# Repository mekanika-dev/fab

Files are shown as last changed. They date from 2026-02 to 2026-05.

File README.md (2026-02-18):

# Fab CNC

> Fab is a large-format CNC milling machine to boost your production. It allows you to produce a wide range of materials every day at high speed and with precision.

- [Assembly Guide & Documentation](https://support.mekanika.io/products/fab-cnc)
- [Shop](https://www.mekanika.io/en/store/be/fab/)
- [Contact](https://www.mekanika.io/contact-us/)

Fab CNC Milling Machine

## Repository Structure

- **`bom/`** - Bill of Materials
- **`cad/`** - CAD files
- **`docs/`** - Documentation files

The Bill of Materials is available as a CSV file, which is dynamically updated from our ERP. We recommend using this **[web viewer](https://mekanika-dev.github.io/data-sync-actions/odoo/bom-viewer.html)** to browse its content.

All 3D assembly files are made in STEP format and compatible with many CAD software. Please note that you will need Git LFS installed to clone or pull the repo correctly, since these files exceed 100MB.

The design files can also be viewed in web browsers using these links:

- [Fab](https://a360.co/4mOqgvm)
- [Fab Control Unit](https://a360.co/46sqwel)

## Assembly Guide

The assembly guide is available on our [support website](https://support.mekanika.io/products/fab-cnc). If you have feedback or want to raise an issue about a specific assembly step, you can use the feedback buttons available on each step's page.

## Community

Mekanika encourages collaborative design and innovation. We welcome:

- Designers and engineers to contribute
- Feedback on design variations
- Any discussions around or products and potential improvements

Don't hesitate to join us on our [Discord](https://discord.gg/n7RsBtUdGc)

## License

This project is licensed under the **CERN Open Hardware Licence Version 2 - Strongly Reciprocal** ([CERN-OHL-S v2](https://ohwr.org/cern_ohl_s_v2.pdf))

For the complete license terms, see REUSE.toml

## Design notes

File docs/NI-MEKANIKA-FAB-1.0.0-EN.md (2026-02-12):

---
title: "USER MANUAL: CNC FAB"
css: style.css
---

<div class="cover-page" style="text-align: center;">

Logo Mekanika

<h4 style="margin-bottom: 0;">3-AXIS CNC MILLING MACHINE</h4>

<hr style="width: 200px; margin: 10px auto; color:#000 !important;"/>

<h4 style="margin-top: 0;">FAB MODEL V1.0</h4>

Fab ISO View

**ORIGINAL MANUAL**
<br/>
Version: 1.0.0-EN
<br/>
Revision Date: November 2025

</div>

## TABLE OF CONTENTS

#### 1. GENERAL INFORMATION

<ul style="list-style-type: none;">
  <li>1.1 <a href="#11-manufacturer-identification">Manufacturer identification</a></li>
  <li>1.2 <a href="#12-ce-declaration-of-conformity">CE Declaration of Conformity</a></li>
  <li>1.3 <a href="#13-intended-use">Intended use</a>
    <ul style="list-style-type: none;">
      <li>1.3.1 <a href="#131-normal-use">Normal Use</a></li>
      <li>1.3.2 <a href="#132-prohibited-uses">Prohibited uses</a></li>
    </ul>
  </li>
  <li>1.4 <a href="#14-authorized-personnel">Authorized personnel</a>
    <ul style="list-style-type: none;">
      <li>1.4.1 <a href="#141-minimum-requirements">Minimum requirements</a></li>
      <li>1.4.2 <a href="#142-restrictions">Restrictions</a></li>
    </ul>
  </li>
</ul>

#### 2. SAFETY

<ul style="list-style-type: none;">
  <li>2.1 <a href="#21-safety-instructions-by-risk-level">Safety instructions by risk level</a></li>
  <li>2.2 <a href="#22-personal-protective-equipment">Personal protective equipment</a>
    <ul style="list-style-type: none;">
      <li>2.2.1 <a href="#221-mandatory-ppe">Mandatory PPE</a></li>
      <li>2.2.2 <a href="#222-dress-code">Dress Code</a></li>
    </ul>
  </li>
  <li>2.3 <a href="#23-safety-devices">Safety devices</a>
    <ul style="list-style-type: none;">
      <li>2.3.1 <a href="#231-emergency-stop">Emergency stop</a></li>
      <li>2.3.2 <a href="#232-limit-switches">Limit switches</a></li>
      <li>2.3.3 <a href="#233-dust-shoe">Dust shoe</a></li>
    </ul>
  </li>
</ul>

#### 3. TECHNICAL DESCRIPTION

<ul style="list-style-type: none;">
  <li>3.1 <a href="#31-overview">Overview</a>
    <ul style="list-style-type: none;">
      <li>3.1.1 <a href="#311-axis-diagram">Axis diagram</a></li>
      <li>3.1.2 <a href="#312-control-box-diagram">Control box diagram</a></li>
    </ul>
  </li>
  <li>3.2 <a href="#32-technical-specifications">Technical specifications</a></li>
</ul>

#### 4. INSTALLATION & ASSEMBLY

<ul style="list-style-type: none;">
  <li>4.1 <a href="#41-unpacking-and-inspection">Unpacking and inspection</a>
    <ul style="list-style-type: none;">
      <li>4.1.1 <a href="#411-upon-receipt">Upon receipt</a></li>
      <li>4.1.2 <a href="#412-kit-inventory">Kit inventory</a></li>
    </ul>
  </li>
  <li>4.2 <a href="#42-assembly">Assembly</a>
    <ul style="list-style-type: none;">
      <li>4.2.1 <a href="#421-preparation">Preparation</a></li>
    </ul>
  </li>
  <li>4.3 <a href="#43-installation">Installation</a>
    <ul style="list-style-type: none;">
      <li>4.3.1 <a href="#431-recommended-layout">Recommended layout</a></li>
      <li>4.3.2 <a href="#432-room-requirements">Room requirements</a></li>
    </ul>
  </li>
</ul>

#### 5. INITIAL STARTUP

<ul style="list-style-type: none;">
  <li>5.1 <a href="#51-preliminary-checks">Preliminary checks</a>
    <ul style="list-style-type: none;">
      <li>5.1.1 <a href="#511-safety-checklist">Safety checklist</a></li>
    </ul>
  </li>
  <li>5.2 <a href="#52-first-power-on">First power-on</a>
    <ul style="list-style-type: none;">
      <li>5.2.1 <a href="#521-startup-sequence">Startup sequence</a></li>
    </ul>
  </li>
  <li>5.3 <a href="#53-functional-test">Functional test</a></li>
</ul>

#### 6. OPERATION

<ul style="list-style-type: none;">
  <li>6.1 <a href="#61-checklist-for-safe-machine-operation">Checklist for safe machine operation</a>
    <ul style="list-style-type: none;">
      <li>6.1.1 <a href="#611-daily-startup">Daily startup</a></li>
    </ul>
  </li>
  <li>6.2 <a href="#62-workpiece-clamping">Workpiece clamping</a>
    <ul style="list-style-type: none;">
      <li>6.2.1 <a href="#621-clamping-systems-supplied-with-base-kit">Clamping systems supplied with base kit</a></li>
      <li>6.2.2 <a href="#622-clamping-rules">Clamping rules</a></li>
    </ul>
  </li>
  <li>6.3 <a href="#63-tool-installation">Tool installation</a>
    <ul style="list-style-type: none;">
      <li>6.3.1 <a href="#631-tool-change">Tool change</a></li>
      <li>6.3.2 <a href="#632-tool-length-measurement">Tool length measurement</a></li>
    </ul>
  </li>
  <li>6.4 <a href="#64-programming-and-machining">Programming and machining</a>
    <ul style="list-style-type: none;">
      <li>6.4.1 <a href="#641-accepted-formats">Accepted formats</a></li>
      <li>6.4.2 <a href="#642-operating-modes">Operating modes</a></li>
    </ul>
  </li>
  <li>6.5 <a href="#65-monitoring-during-machining">Monitoring during machining</a>
    <ul style="list-style-type: none;">
      <li>6.5.1 <a href="#651-check-points">Check points</a></li>
      <li>6.5.2 <a href="#652-anomalies-and-actions">Anomalies and actions</a></li>
    </ul>
  </li>
</ul>

#### 7. ADD-ONS AND OPTIONS

<ul style="list-style-type: none;">
  <li>7.1 <a href="#71-vacuum-table">Vacuum table</a>
    <ul style="list-style-type: none;">
      <li>7.1.1 <a href="#711-specifications">Specifications</a></li>
      <li>7.1.2 <a href="#712-use">Use</a></li>
    </ul>
  </li>
  <li>7.2 <a href="#72-dust-collection-kit">Dust collection kit</a>
    <ul style="list-style-type: none;">
      <li>7.2.1 <a href="#721-specifications">Specifications</a></li>
    </ul>
  </li>
  <li>7.3 <a href="#73-laser-module-lsr">Laser module (LSR)</a>
    <ul style="list-style-type: none;">
      <li>7.3.1 <a href="#731-specifications">Specifications</a></li>
    </ul>
  </li>
</ul>

#### 8. MAINTENANCE & TROUBLESHOOTING

<ul style="list-style-type: none;">
  <li>8.1 <a href="#81-preventive-maintenance-plan">Preventive maintenance plan</a></li>
  <li>8.2 <a href="#82-lubrication">Lubrication</a></li>
  <li>8.3 <a href="#83-spare-parts">Spare parts</a></li>
</ul>

#### 9. TROUBLESHOOTING

<ul style="list-style-type: none;">
  <li>9.1 <a href="#91-troubleshooting-and-diagnostics">Troubleshooting and diagnostics</a></li>
  <li>9.2 <a href="#92-technical-support">Technical support</a>
    <ul style="list-style-type: none;">
      <li>9.2.1 <a href="#921-before-contacting-support">Before contacting support</a></li>
    </ul>
  </li>
</ul>

#### 10. TRANSPORTATION & STORAGE

<ul style="list-style-type: none;">
  <li>10.1 <a href="#101-machine-transportation">Machine Transportation</a></li>
  <li>10.2 <a href="#102-packaging--waste">Packaging & Waste</a></li>
  <li>10.3 <a href="#103-storage">Storage</a></li>
</ul>

## 1. GENERAL INFORMATION {#1-general-information}

### 1.1 Manufacturer identification {#11-manufacturer-identification}

**Mekanika SRL**

Chaussée de Mons 1281  
1070 Anderlecht, Belgium  
VAT No.: BE0740501760

**Contact:**

<ul style="list-style-type: none;">
<li><i class="fas fa-envelope" style="color: #2196f3;"></i> info@mekanika.io</li>
<li><i class="fas fa-globe" style="color: #2196f3;"></i> www.mekanika.io</a></li>
</ul>

### 1.2 CE Declaration of Conformity {#12-ce-declaration-of-conformity}

This machine complies with the following European directives:

- **2006/42/EC** - Machinery Directive
- **2014/30/EU** - Electromagnetic Compatibility (EMC) Directive

**Harmonized standards applied:**

- **EN ISO 12100:2010** - Safety of machinery, General principles
- **EN 60204-1:2006** - Electrical safety of machinery
- **EN ISO 13850:2015** - Emergency stop function
- **EN 848-3:2012** - Safety of woodworking machines (partially)
- **EN 61000-6-1** - EMC Immunity
- **EN 61000-6-3** - EMC Emissions

The original declaration of conformity is supplied with this machine.

### 1.3 Intended use {#13-intended-use}

Please read this instruction manual and all accompanying documents in their entirety before commissioning the machine.

If in doubt or if you need additional information, please do not hesitate to contact us before using the machine.

#### 1.3.1 Normal Use {#131-normal-use}

The MEKANIKA FAB CNC milling machine is a 3-axis CNC machine intended for:

<ul style="list-style-type: none; margin-left: 0.75em">
  <li><i class="fas fa-square-check" style="color: #4EBD7D;"></i> Machining of wood and derivatives (plywood, MDF, OSB)</li>
  <li><i class="fas fa-square-check" style="color: #4EBD7D;"></i> Machining of plastics (PVC, acrylic, polycarbonate)</li>
  <li><i class="fas fa-square-check" style="color: #4EBD7D;"></i> Machining of non-ferrous metals (aluminum, brass)</li>
  <li><i class="fas fa-square-check" style="color: #4EBD7D;"></i> Machining of composite materials (with special precautions)</li>
</ul>

#### 1.3.2 Prohibited uses {#132-prohibited-uses}

The following uses are **PROHIBITED:**

<ul style="list-style-type: none; margin-left: 0.75em">
  <li><i class="fas fa-xmark" style="color: #d32f2f;"></i> Machining of unknown composite materials or materials containing asbestos</li>
  <li><i class="fas fa-xmark" style="color: #d32f2f;"></i> Use in explosive atmospheres</li>
  <li><i class="fas fa-xmark" style="color: #d32f2f;"></i> Outdoor or humid environment use</li>
  <li><i class="fas fa-xmark" style="color: #d32f2f;"></i> Machining of improperly secured workpieces</li>
  <li><i class="fas fa-xmark" style="color: #d32f2f;"></i> Machining beyond the machine's technical capabilities</li>
</ul>

### 1.4 Authorized personnel {#14-authorized-personnel}

#### 1.4.1 Minimum requirements {#141-minimum-requirements}

- **Minimum age:** 16 years
- **Required training:**
  - Complete reading of this manual
  - Completed online training (series of free video tutorials)
  - Basic CAM knowledge
- **Physical abilities:**
  - Normal or corrected vision
  - Normal or aided hearing
  - Sufficient mobility to access the emergency stop

#### 1.4.2 Restrictions {#142-restrictions}

- Prohibition for untrained persons
- Prohibition for persons under the influence (alcohol, drugs, medication)
- Mandatory supervision for persons learning on the machine

## 2. SAFETY {#2-safety}

Read the entire user manual to familiarize yourself with the machine's features and how to use them. Incorrect operation of the machine can result in damage to the machine, your personal property and cause serious injury, electric shock and/or fire.

**It is imperative to comply at all times with the safety instructions listed in this operating manual.**

### 2.1 Safety instructions by risk level {#21-safety-instructions-by-risk-level}

The following terms are used in this user manual to indicate different levels of potential danger when using this machine. The safety symbols and their explanations require your attention.

Safety warnings do not eliminate any danger. The instructions or warnings they give are not a substitute for appropriate preventive measures.

> **<i class="fas fa-ban" style="color: #d32f2f;"></i> DANGER** - _Instructions which, if not properly followed, create a probability of property damage, collateral damage, serious injury or death or create a high probability of minor injury._

| **TYPE OF RISK** | **SAFETY INSTRUCTIONS** |
| :--- | :--- |
| **Risk of electrocution** | Machine plugs must match the power outlet used. Never modify the plug in any way. Do not use adapter plugs with grounded machines. |
| **Risk of electrocution - indirect contact** | An insulation fault can energize normally non-conductive metal parts (chassis, structure, housing). Causes include: cable wear in cable chains, moisture infiltration, accumulation of conductive dust, failing components, or mechanical damage. Never use the machine if: <br/> - The circuit breaker trips repeatedly; <br/> - Traces of electrical arcing are visible (blackening, burning smell); <br/> - Moisture/condensation is visible in the housing. |
| **Toxic dust** | Some dusts created when machining certain types of materials may contain chemicals known to cause cancer, birth defects or other reproductive harm. Always research the material you are working with before machining it. Examples of these chemicals include: lead from non-ferrous metals containing lead, carbonate from carbon fiber, arsenic and chromium from chemically treated wood.<br><br>The risk you face from exposure varies depending on how often you perform this type of work. To reduce your exposure to these chemicals: work in a well-ventilated area and use approved safety equipment, such as dust masks specifically designed to filter microscopic particles. |
| **Explosive atmosphere** | Do not operate the machine in explosive atmospheres, such as in the presence of flammable liquids, gases or dusts. Machines can create sparks which may ignite dusts or fumes. |

> **<i class="fas fa-exclamation-triangle" style="color: #ff9800;"></i> WARNING** - _Instructions which, if not properly followed, create a probability of property damage and a possibility of serious injury._

| **TYPE OF RISK** | **SAFETY INSTRUCTIONS** |
| :--- | :--- |
| **Clothing** | Dress appropriately. Do not wear loose clothing or jewelry. Pin your hair above your shoulders so it cannot get caught in linear guides or moving parts. |
| **Vigilance** | Stay alert, watch what you are doing and use common sense when operating a machine. Do not use a machine when you are tired and/or under the influence of drugs, alcohol or medication. A moment of inattention while using a machine can result in serious injury. |
| **Personal protection** | Use personal protective equipment. Always wear eye protection. Protective equipment such as a dust mask or appropriate hearing protection reduces the risk of injury. |
| **Machine control** | This machine is controlled by a computer. During operation, it cannot be controlled directly. Lack of caution or expertise as well as program errors can result in unexpected movements. |
| **Rotating tool** | Do not touch the rotating tool area. The proximity of the rotating tool to your hand is not always obvious. |
| **Tool blocking** | If the workpiece or end mill becomes blocked, immediately press the emergency stop button. Wait for all moving parts to stop and for the spindle to be turned off, then free the jammed material. Do not attempt to do this while the spindle is running. |
| **Hot tools** | Do not touch the end mill or collet after use. After use, they are too hot to touch with bare hands. |
| **Hot surfaces** | Do not touch the motors, as they can heat up during machine operation. |
| **Tool handling** | Be careful when handling tools, they can be very sharp. Never place any part of the tool or accessories in your mouth, as this can result in serious injury. |
| **Workpiece clamping** | Before starting any machining operation, always firmly clamp your workpiece. Never try to hold the workpiece by hand or with accessories. These tools can easily jam in the material and can kick back, resulting in loss of control and serious injury. |
| **Limit sensors** | Never try to reach the limit sensors when the machine is in motion, this could result in crushing of your hand or fingers. |
| **Prohibited modifications** | Do not modify your machine, or use it in a manner not intended by the manufacturer. Any alteration or modification constitutes misuse and may result in serious injury. |
| **Lockout** | Disconnect the plug from the power source before making adjustments, changing accessories or disassembling the machine. |
| **Machine access** | Keep the machine out of reach of children and do not allow persons unfamiliar with these instructions to use the machine. Machines are dangerous in the hands of untrained users. |
| **Safety distance** | Keep children and bystanders at a distance. Distractions can cause you to lose control and cause accidents. |

> **<i class="fas fa-info-circle" style="color: #2196f3;"></i> CAUTION** - _Instructions which, if not properly followed, create a possibility of property damage and a possibility of minor injury._

| **TYPE OF RISK** | **SAFETY INSTRUCTIONS** |
| :--- | :--- |
| **Mandatory training** | All persons who use the machine must have read and fully understood all relevant safety and operating instructions. Any misunderstanding can result in injury. |
| **Cleanliness and lighting** | Keep the work area clean and well lit. Cluttered or dark areas are conducive to accidents. |
| **Indoor use** | Only operate the machine in indoor spaces. |
| **Moisture protection** | Do not expose the machine to moisture. The machine can only be used indoors. |
| **Supervision** | Do not leave the machine running unattended, and cut the spindle power if you leave. The machine is only secure when it is completely stopped and disconnected from the mains. |
| **Proper use** | Use the machine and its accessories in accordance with this manual, taking into account the working conditions and the work to be performed. Using the machine for operations other than those intended may result in a hazardous situation with a high probability of injury. |
| **Tool condition** | Never use dull or damaged end mills. Damaged end mills can break during use. Dull end mills require more force to cut, which can result in end mill breakage. |
| **Machining parameters** | The speed and feed rate of the end mill during engraving, profiling or cutting are very important. Always observe the recommended speed and feed rate for a particular end mill/machine/operation configuration. |
| **Ventilation** | Remember to clean the ventilation openings of the control boxes using compressed air. Excessive dust accumulation inside the boxes can cause electrical failures. |
| **Preventive maintenance** | Properly maintain the tools you use. Check for misalignment or binding of moving parts, broken parts and any other condition that may affect the operation of the machine. If damaged, have the machine repaired before using it. Many accidents are caused by poorly maintained machines. |
| **Repairs** | Have your machine repaired by a qualified technician using only identical replacement parts. |

### 2.2 Personal protective equipment {#22-personal-protective-equipment}

#### 2.2.1 Mandatory PPE {#221-mandatory-ppe}

| Equipment | Use | Pictogram |
| :--- | :--- | :---: |
| **Safety glasses** | Recommended during machining | Safety glasses |
| **Hearing protection** | Recommended during machining, mandatory if noise level > 80 dB(A) | Hearing protection |
| **Gloves** | Recommended when handling parts/tools | Gloves |
| **FFP2 mask** | Mandatory when machining composite materials | FFP2 mask |
| **Safety shoes** | Recommended for all work in front of a machine | Safety shoes |

#### 2.2.2 Dress Code {#222-dress-code}

**<i class="fas fa-square-check" style="color: #4EBD7D;"></i> MANDATORY:**

- Fitted clothing
- Short sleeves or rolled up
- Long hair tied back or under a cap

**<i class="fas fa-xmark" style="color: #d32f2f;"></i> PROHIBITED:**

- Jewelry (rings, necklaces, bracelets)
- Loose clothing
- Ties, scarves
- Gloves during machining

### 2.3 Safety devices {#23-safety-devices}

#### 2.3.1 Emergency stop {#231-emergency-stop}

**Characteristics:**

- Type: Lockable push button
- Color: Red on yellow background
- Standard: EN ISO 13850:2015
- Position: Front face, easily accessible

**Operation:**

1. **Activation:** Press the red button
   - Immediate stop of all movements
   - Spindle cutoff
   - Machine control software lockout
2. **Reset:** Turn the button clockwise
   - The program must be restarted manually

#### 2.3.2 Limit switches {#232-limit-switches}

**Configuration:**

- 6 NC PNP inductive sensors
- 2 sensors on X and Y axes (min/max) with AND logic for redundant safety

**Triple function:**

1. **Homing:** Machine referencing at startup
2. **Safety:** Emergency stop if limit reached
3. **Square gantry:** Gantry squaring

#### 2.3.3 Dust shoe {#233-dust-shoe}

**Dual function:**

- Protection against access to the tool
- Chip and dust extraction

> **<i class="fas fa-info-circle" style="color: #2196f3;"></i> CAUTION** - _Never remove the dust shoe during machining_

## 3. TECHNICAL DESCRIPTION {#3-technical-description}

### 3.1 Overview {#31-overview}

The MEKANIKA FAB is a 3-axis CNC milling machine, allowing material to be machined by moving along the X, Y and Z axes, or a combination of these by linear interpolation.

#### 3.1.1 Axis diagram {#311-axis-diagram}

Axis diagram

**Axis terminology:**

- **X axis:** Lateral movement (left-right)
- **Y axis:** Longitudinal movement (front-back)
- **Z axis:** Vertical movement (up-down)

#### 3.1.2 Control box diagram {#312-control-box-diagram}

Control box diagram

**Connector description:**

- **1**: Fan
- **2**: Motors
- **3**: Limit switches
- **4**: Emergency stop
- **5**: Tool probe (Input 1)
- **6**: Spindle control
- **7**: Input 2
- **8**: Input 3
- **9**: Laser control
- **10**: HDMI
- **11**: USB 2.0
- **12**: Ethernet
- **13**: Power supply
- **14**: Ground connection

### 3.2 Technical specifications {#32-technical-specifications}

| **CHARACTERISTIC** | **VALUE** |
| :--- | :--- |
| **MACHINE DIMENSIONS** | |
| Overall dimensions | 1750 × 3150 × 1250 mm |
| Total weight | 180 kg |
| **WORK AREA** | |
| Machinable surface | 1330 x 2700 mm |
| Table-spindle distance (max) | 110 mm |
| **PERFORMANCE** | |
| Max travel speed | 20000 mm/min |
| Recommended machining speed  | 100 - 10000 mm/min |
| **MECHANICS** | |
| Linear guides | Double prismatic rail HGR20 |
| X & Z transmission | Ball screws 16 mm (C7) |
| Y transmission | Double rack and pinion (Mod 2) |
| Structure | Aluminum profiles + steel plates |
| **MOTORS** | |
| X & Y motors | NEMA34 6A |
| Z motors | NEMA23 5A |
| **SPINDLE** | |
| Power | 2.2 kW |
| Cooling | Air |
| Rotation speed | 6000 - 24000 rpm |
| Collet | ER20 (1-13 mm) |
| Control | Variable frequency drive (VFD) |
| **ELECTRICAL** | |
| Power supply | 230V AC single phase, 50 Hz |
| Maximum power | 3.5 kW |
| Protection | 16A fuse, mandatory grounding |
| **ENVIRONMENT** | |
| Operating temperature | 5°C to 35°C |
| Relative humidity | 40-60% |
| Use | Indoor only |

## 4. INSTALLATION & ASSEMBLY {#4-installation--assembly}

### 4.1 Unpacking and inspection {#41-unpacking-and-inspection}

#### 4.1.1 Upon receipt {#411-upon-receipt}

**Check immediately:**

1. The condition of the packaging (photos if damaged)
2. The presence of all packages (see delivery note)
3. The absence of apparent damage

#### 4.1.2 Kit inventory {#412-kit-inventory}

We strongly recommend that you inventory your kit before starting assembly. The list of parts grouped by packaging is available on our website:

<br>
<i class="fas fa-globe" style="color: #2196f3;"></i> [support.mekanika.io/products/fab-cnc/kit-content](support.mekanika.io/products/fab-cnc/kit-content)

### 4.2 Assembly {#42-assembly}

Please carefully follow our online assembly guide to properly assemble your Mekanika machine.
<br>
<i class="fas fa-globe" style="color: #2196f3;"></i> [support.mekanika.io/products/fab-cnc/assembly-guide](support.mekanika.io/products/fab-cnc/assembly-guide)

#### 4.2.1 Preparation {#421-preparation}

- **Required space:** 3 × 4 m minimum
- **Estimated time:** 25 hours (alone) - 15 hours (2 people)
- **Required tools:** Provided in the kit

> **<i class="fas fa-exclamation-triangle" style="color: #ff9800;"></i> RISK** - There is a significant risk of heavy parts falling during assembly. Please handle heavy parts with a minimum of 2 people.

> **<i class="fas fa-info-circle" style="color: #2196f3;"></i> CAUTION** - Please follow the precise order of assembly steps to avoid risks of machine malfunction.

### 4.3 Installation {#43-installation}

#### 4.3.1 Recommended layout {#431-recommended-layout}

Place the machine on a level and stable floor. To ensure a comfortable working height, we recommend a working height of approximately 85 cm.

All moving parts of the machine must be able to operate without collision.

The machine must be easily accessible and usable. In particular, the emergency stop button must be easily accessible at all times.

**Zone description:**

- **1**: Operating zone
- **2**: Loading zone
- **3**: Maintenance and safety zone

Work area

#### 4.3.2 Room requirements {#432-room-requirements}

**Floor:**

- Flatness: < 5 mm/m
- Capacity: > 200 kg/m²
- Type: Concrete recommended

**Environment:**

- Temperature: 18-25°C ideal
- Humidity: 40-60%
- Lighting: > 500 lux on work area
- Ventilation: Adequate air renewal

## 5. INITIAL STARTUP {#5-initial-startup}

Before commissioning, the machine and all connected components must be properly wired and in perfect condition.

The operator must have read and understood the complete documentation of the relevant machine model and corresponding instructions. In addition, they must have been trained in the operation of the machine and its accessories and must be familiar with the use of the CNC milling machine and PlanetCNC software in general.

### 5.1 Preliminary checks {#51-preliminary-checks}

> **<i class="fas fa-info-circle" style="color: #2196f3;"></i> CAUTION** - Never power on before these checks

#### 5.1.1 Safety checklist {#511-safety-checklist}

**Mechanical:**

<ul style="list-style-type: none; margin-left: 0.75em">
  <li><i class="fas fa-square-check" style="color: #4EBD7D;"></i> Tightening of all fasteners</li>
  <li><i class="fas fa-square-check" style="color: #4EBD7D;"></i> Freedom of movement of axes (manual rotation)</li>
  <li><i class="fas fa-square-check" style="color: #4EBD7D;"></i> Absence of abnormal play</li>
  <li><i class="fas fa-square-check" style="color: #4EBD7D;"></i> Guides and ball screws lubricated</li>
</ul>

**Electrical:**

<ul style="list-style-type: none; margin-left: 0.75em">
  <li><i class="fas fa-square-check" style="color: #4EBD7D; "></i> Ground continuity (< 0.1 Ω)</li>
  <li><i class="fas fa-square-check" style="color: #4EBD7D;"></i> Cable insulation</li>
  <li><i class="fas fa-square-check" style="color: #4EBD7D;"></i> Tight connections</li>
  <li><i class="fas fa-square-check" style="color: #4EBD7D;"></i> Mains differential protection tested</li>
</ul>

**Safety:**

<ul style="list-style-type: none; margin-left: 0.75em">
  <li><i class="fas fa-square-check" style="color: #4EBD7D;"></i> Emergency stop accessible and functional</li>
  <li><i class="fas fa-square-check" style="color: #4EBD7D;"></i> Limit switches connected</li>
  <li><i class="fas fa-square-check" style="color: #4EBD7D;"></i> Dust shoe installed</li>
  <li><i class="fas fa-square-check" style="color: #4EBD7D;"></i> Work area clear</li>
</ul>

### 5.2 First power-on {#52-first-power-on}

#### 5.2.1 Startup sequence {#521-startup-sequence}

**1. Preparation**

- Clear area in front and around the machine
- PPE worn
- Documentation within reach

**2. Power-on**

- Check that emergency stop is unlocked
- Turn on control box
- Wait for Raspberry Pi initialization
- Wait for PlanetCNC to launch

**3. Initial checks**

- Control box fans rotating
- Limit switch indicators lit
- Touchscreen on and PlanetCNC interface active
- Emergency stop button functional

### 5.3 Functional test {#53-functional-test}

We strongly recommend following our illustrated machine startup guide, available on our website:
<br>
<i class="fas fa-globe" style="color: #2196f3;"></i> [support.mekanika.io/products/fab-cnc/get-started](https://support.mekanika.io/products/fab-cnc/get-started)

This includes all the necessary information to test the machine at first use, as well as useful information about its operation and safety features.

## 6. OPERATION {#6-operation}

The Fab CNC milling machine is intended for regular and professional use. Thanks to the rigidity of the machine, it is possible to process a variety of different materials, such as wood and non-ferrous metals.

The plausible and reasonable scope of uses includes:

- Manual movement mode, using a digital "jog" to move the machine along its 3 axes independently.
- The automatic positioning procedure, performed by the user by clicking a digital button. This procedure sequentially moves the machine on each of its axes in the following order: Z, X, Y, until it encounters the limit switches.
- The tool length measurement procedure, activated by the user by clicking a digital button. This procedure lowers the machine at reduced speed along its Z axis until its tool comes into contact with a removable sensor previously placed by the user.
- Normal operating mode, where the machine moves automatically according to a machine language, called G-code, previously loaded by the user.
- Manual control mode using a terminal allowing the machine to move according to a machine language, called G-code, entered directly by the user.

The plausible and reasonable scope of interventions includes:

- Manual movement of the machine to access certain areas.
- Calibration of the rack system using the compression spring.
- Tool change on the spindle.
- Attachment or removal of the dust shoe.
- Attachment or removal of material to be machined.
- Starting, pausing and stopping G-Code.
- Connection/disconnection of external machine cables.
- Opening cable chains to access the machine.

### 6.1 Checklist for safe machine operation {#61-checklist-for-safe-machine-operation}

#### 6.1.1 Daily startup {#611-daily-startup}

**1. Inspection and equipment**

- Inspect the equipment to ensure it has no obvious defects, damaged chucks, dull or cracked tools
- Use appropriate PPE (glasses, helmet,...)
- Tie back long hair and wear well-fitted clothing and roll up your sleeves to avoid snags

**2. Machine preparation**

- Check where the emergency stop button is located
- Never plug or unplug cables from the electronic box when the device is powered on
- Ensure the workpiece is firmly and securely clamped
- Check that the end mill is sharp and firmly tightened in the spindle chuck
- When handling or changing end mills, avoid touching the cutting edges
- Keep your hands free during manual adjustments

**3. During use**

- Never touch the machine when it is running and keep your hands away from any moving parts during machining
- Stay away from the machine when it is operational

**4. After machining**

- Use a brush or vacuum to clean chips from surfaces
- If linear guides, ball screws and racks are dusty, blow them with compressed air to keep them clean and unobstructed by chips
- Clean the floor and work area around the machine
- Clean and store personal protective equipment
- Mark any defective equipment and contact us if you encounter a problem

**5. Normal shutdown**

1. Complete current machining
2. Stop spindle
3. **Shut down Raspberry Pi** (proper shutdown)
4. Wait 30 seconds
5. Turn off control box

> **<i class="fas fa-info-circle" style="color: #2196f3;"></i> CAUTION** - Follow the order to avoid corruption of the Raspberry Pi SD card

**6. Emergency stop**

**In case of danger:**

1. **Immediately press** the red button
2. Cut power if necessary
3. Analyze the situation
4. Correct the problem
5. Reset (turn the button)
6. Redo a homing procedure

### 6.2 Workpiece clamping {#62-workpiece-clamping}

#### 6.2.1 Clamping systems supplied with base kit {#621-clamping-systems-supplied-with-base-kit}

**Wood screws:**

- For soft materials
- Direct screwing into spoilerboard
- Regular spacing

**Clamps with inserts:**

- For all materials
- M6 inserts in spoilerboard

#### 6.2.2 Clamping rules {#622-clamping-rules}

**<i class="fas fa-square-check" style="color: #4EBD7D;"></i> GOOD PRACTICES:**

- Minimum 4 clamping points
- Symmetrical distribution
- Check before machining

**<i class="fas fa-xmark" style="color: #d32f2f;"></i> PROHIBITIONS:**

- Manual clamping
- Adhesive alone
- Overhanging workpiece
- Excessive tightening (deformation)

> **<i class="fas fa-ban" style="color: #d32f2f;"></i> DANGER** - During machining, NEVER hold the workpiece by hand

### 6.3 Tool installation {#63-tool-installation}

#### 6.3.1 Tool change {#631-tool-change}

**Procedure:**

1. Wait for complete stop or machine pause
2. Move Z axis to high position
3. Unlock ER20 nut (supplied wrenches)
4. Remove tool (gloves strongly recommended)
5. Insert new tool
6. Tighten firmly (without excess)

#### 6.3.2 Tool length measurement {#632-tool-length-measurement}

**With the supplied tool probe:**

1. Place the probe on the workpiece or spoilerboard (depending on the Z0 coordinate defined in the program)
2. Position the spindle above the probe
3. Press the tool length measurement icon
4. Slow automatic descent
5. Contact and memorization of new Z0 position

### 6.4 Programming and machining {#64-programming-and-machining}

#### 6.4.1 Accepted formats {#641-accepted-formats}

- **G-code:** .nc, .ngc, .gcode
- **Generation:** Via any CAM software. Some examples:
  - Fusion 360 (recommended)
  - VCarve
  - FreeCAD
  - Others

#### 6.4.2 Operating modes {#642-operating-modes}

**Automatic mode:**

1. Load G-code file
2. Check simulation in PlanetCNC
3. Position workpiece origin (X0 Y0 Z0)
4. Start program (Start)

**Manual mode (JOG):**

- Movement by axes
- Variable speed (10-100%)
- Movement by increments possible (examples: 0.01, 0.1, 1, 10 mm)

**MDI mode:**

- Sending direct G-code commands
- Sequence testing
- Precise positioning

### 6.5 Monitoring during machining {#65-monitoring-during-machining}

#### 6.5.1 Check points {#651-check-points}

- Abnormal vibrations
- Unusual noise
- Chip quality
- Temperature near tool
- Workpiece clamping

#### 6.5.2 Anomalies and actions {#652-anomalies-and-actions}

| Anomaly | Probable cause | Immediate action |
| :--- | :--- | :--- |
| **Vibrations** | Worn tool or unsuitable cutting parameters | STOP → Check tool and parameters |
| **Smoke** | Worn tool or unsuitable cutting parameters | EMERGENCY → Stop |
| **Loud noise** | Very worn or broken tool | EMERGENCY → Stop |
| **Moving workpiece** | Insufficient clamping | EMERGENCY → Stop |

> In case of doubt → **IMMEDIATE STOP**

## 7. ADD-ONS AND OPTIONS {#7-add-ons-and-options}

### 7.1 Vacuum table {#71-vacuum-table}

#### 7.1.1 Specifications {#711-specifications}

- Plastic plenum with dedicated spoilerboard and integrated seals
- 5 independent zones
- Vacuum pump and connections
- Installation: 3 hours

#### 7.1.2 Use {#712-use}

**New clamping system for workpieces:**

1. Place workpiece on spoilerboard
2. Open necessary zones
3. Activate vacuum pump
4. Check hold (manual test)

Information about the kit and assembly guide can be found on our website:

<i class="fas fa-globe" style="color: #2196f3;"></i> [support.mekanika.io/products/vacuum-table/vacuum-table-fab](https://support.mekanika.io/products/vacuum-table/vacuum-table-fab)

We strongly recommend following our illustrated startup guide dedicated to the vacuum table.

### 7.2 Dust collection kit {#72-dust-collection-kit}

#### 7.2.1 Specifications {#721-specifications}

- Anti-static suction hose Ø100mm
- Compatible with most workshop vacuums
- Pivoting steel tube support
- Installation: 1 hour

Information about the kit and assembly guide can be found on our website:

<i class="fas fa-globe" style="color: #2196f3;"></i> [support.mekanika.io/products/dust-collection-kit](https://support.mekanika.io/products/dust-collection-kit)

### 7.3 Laser module (LSR) {#73-laser-module-lsr}

#### 7.3.1 Specifications {#731-specifications}

- Model: PLH3D-XT-50
- Power: 6W optical
- Wavelength: 445 nm (blue)
- Laser class: 4

> **<i class="fas fa-ban" style="color: #d32f2f;"></i> DANGER - CLASS 4 LASER**
>
> **Dedicated documentation:** See separate manual supplied with the machine

Information about the kit and assembly guide can be found on our website:

<i class="fas fa-globe" style="color: #2196f3;"></i> [support.mekanika.io/products/laser-head-6w](https://support.mekanika.io/products/laser-head-6w)

## 8. MAINTENANCE & TROUBLESHOOTING {#8-maintenance--troubleshooting}

We strongly recommend following our video maintenance guide, available on our website:

<i class="fas fa-globe" style="color: #2196f3;"></i> [support.mekanika.io/products/fab-cnc/maintenance](https://support.mekanika.io/products/fab-cnc/maintenance)

### 8.1 Preventive maintenance plan {#81-preventive-maintenance-plan}

| **FREQUENCY** | **OPERATION** | **DURATION** | **MACHINE STOP** |
| :--- | :--- | :--- | :--- |
| **Daily** | Chip cleaning | 10 min | No |
| **Daily** | General visual inspection | 5 min | No |
| **Monthly** | Lubrication of X/Y/Z guides | 15 min | Yes |
| **Monthly** | Control box filter cleaning | 10 min | Yes |
| **Monthly** | Y belt tension adjustment | 20 min | Yes |
| **Monthly** | Greasing of ball screws and racks | 15 min | Yes |
| **Monthly** | Mechanical play check on linear systems | 30 min | Yes |
| **Monthly** | Complete fastener check | 45 min | Yes |
| **Annual** | Complete machine overhaul | 4h | Yes |
| **Annual** | Bearing replacement if necessary | 2h | Yes |
| **Annual** | Geometric calibration | 2h | Yes |

### 8.2 Lubrication {#82-lubrication}

A linear system must be sufficiently lubricated to function properly and avoid excessive wear or overheating. The required lubrication interval is determined by environmental conditions.

Generally, lubrication is necessary every 100 to 200 hours of operation. We recommend using lithium-based greases, which perform well in high-load applications and have good oxidation stability.

**Procedure:**

1. Clean before greasing (cloth and isopropyl alcohol)
2. Apply grease moderately
3. Perform 10 complete machine travel cycles
4. Wipe off excess grease

### 8.3 Spare parts {#83-spare-parts}

All parts of the machine and control box can be purchased individually as spare parts.

Please contact us directly about this.

When ordering spare parts, please provide information about the machine model, size and part number available according to the construction instructions.

## 9. TROUBLESHOOTING {#9-troubleshooting}

### 9.1 Troubleshooting and diagnostics {#91-troubleshooting-and-diagnostics}

If you have a problem with your machine, please consult our troubleshooting guides available online:

<i class="fas fa-globe" style="color: #2196f3;"></i> [support.mekanika.io/products/fab-cnc/troubleshoot](https://support.mekanika.io/products/fab-cnc/troubleshoot)

### 9.2 Technical support {#92-technical-support}

#### 9.2.1 Before contacting support {#921-before-contacting-support}

**Information to prepare:**

- Machine model (FAB)
- Machine serial number (located under the control box)
- Order number
- Problem description
- Photos/videos if possible

#### **CONTACT FORM**

<i class="fas fa-globe" style="color: #2196f3;"></i> [www.mekanika.io/en/contact-support](https://www.mekanika.io/en/contact-support)

## 10. TRANSPORTATION & STORAGE {#10-transportation--storage}

### 10.1 Machine Transportation {#101-machine-transportation}

If you wish to transport the machine, pay special attention to its dimensions and weight, you may need additional people for transport.

Never lift heavy loads above people.

Avoid loading the machine frame unilaterally during transport.

### 10.2 Packaging & Waste {#102-packaging--waste}

If you do not wish to reuse the device packaging, please sort it according to local sorting rules and take it to a waste collection center for recycling.

If you need to replace certain machine components, or decommission it, please go to your local waste disposal center and perform selective sorting.

| **Material** | **Components** | **Stream** |
| :--- | :--- | :--- |
| **Aluminum** | Profile structure | Metal recycling  |
| **Steel** | Connection plates, shafts, fasteners | Metal recycling  |
| **Electronics**  | Control boards, motors | WEEE\* |
| **Cables** | Sheathed copper | WEEE\* |
| **Plastics** | Cable chains, connection plates | Plastic sorting  |

\* _Waste Electrical and Electronic Equipment_

### 10.3 Storage {#103-storage}

If the machine or its components are not used for an extended period, please observe the following points regarding storage:

- Store the machine and its components only in closed rooms
- Protect the machine and its components from moisture, cold, heat and direct solar radiation
- Store the machine and its components away from dust and cover if necessary
- The storage location must not be subject to vibrations.

---

**END OF INSTRUCTION MANUAL**

This manual is the property of MEKANIKA SRL. Any reproduction, even partial, is prohibited without written authorization.
<br/>

**IMPORTANT NOTES:**

- This manual must remain with the machine
- In case of resale, transmit all documents
- Updates available at [support.mekanika.io/download-center/cnc-milling](https://www.mekanika.io/en/contact-support)
- For any questions: info@mekanika.io
  <br/>

**Keep this manual for future reference**

---

**© 2025 MEKANIKA SRL - All rights reserved**

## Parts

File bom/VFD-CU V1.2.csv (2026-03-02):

level | component_reference | component_name | component_quantity | parent_bom_reference | parent_bom_name | has_child_bom
0 | M00353 | VFD - 2.2kW Inverter Control Unit | 1.00 |  |  | True
1 | M00004 | 220V Inverter | 1.00 | M00353 | VFD - 2.2kW Inverter Control Unit | False
1 | M00355 | CNC Pro/Fab - Steel Parts - VFD Base | 1.00 | M00353 | VFD - 2.2kW Inverter Control Unit | False
1 | M00356 | CNC Pro/Fab - Steel Parts - VFD Cover | 1.00 | M00353 | VFD - 2.2kW Inverter Control Unit | False
1 | M00406 | Circuit Breaker 15A 250V AC | 1.00 | M00353 | VFD - 2.2kW Inverter Control Unit | False
1 | M00720 | Panel Mount IEC C14 Connector with RFI Filter, 15A 250V | 1.00 | M00353 | VFD - 2.2kW Inverter Control Unit | False
1 | M00540 | GX12 male 5 pins output 45cm, panel mount (VFD, Laser) | 1.00 | M00353 | VFD - 2.2kW Inverter Control Unit | False
1 | M00010 | 5V Relay Module, 1 Channel | 1.00 | M00353 | VFD - 2.2kW Inverter Control Unit | False
1 | M00866 | Wago 5 connectors | 1.00 | M00353 | VFD - 2.2kW Inverter Control Unit | False
1 | M01697 | DIN912 M4x12 Black screw | 4.00 | M00353 | VFD - 2.2kW Inverter Control Unit | False
1 | M00746 | Rubber foot M4 | 4.00 | M00353 | VFD - 2.2kW Inverter Control Unit | False
1 | M01702 | Nut DIN934 M4 | 8.00 | M00353 | VFD - 2.2kW Inverter Control Unit | False
1 | M01715 | ISO 7380 M3x4 Black Screw | 6.00 | M00353 | VFD - 2.2kW Inverter Control Unit | False
1 | M00744 | Rocker switch DPST, panel mount | 1.00 | M00353 | VFD - 2.2kW Inverter Control Unit | False
1 | M00809 | Speakon Connector Panel Mount | 1.00 | M00353 | VFD - 2.2kW Inverter Control Unit | False
1 | M01237 | Blue Insulated Female Spade Connector, Receptacle, 4.8 x 0.5mm Tab Size, 1.5mm² to 2.5mm² | 3.00 | M00353 | VFD - 2.2kW Inverter Control Unit | False
1 | M00527 | Fork Spade Terminal 0.5mm² to 1.5mm², 22AWG to 16AWG, M4 Stud Size | 3.00 | M00353 | VFD - 2.2kW Inverter Control Unit | False
1 | M01533 | Dust Filter Mesh, 13cmx20cmx0.375mm, 0.5mm aperture | 2.00 | M00353 | VFD - 2.2kW Inverter Control Unit | False
1 | M01698 | DIN912 M4x16 Black screw | 4.00 | M00353 | VFD - 2.2kW Inverter Control Unit | False

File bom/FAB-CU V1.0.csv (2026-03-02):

level | component_reference | component_name | component_quantity | parent_bom_reference | parent_bom_name | has_child_bom
0 | M00230 | FAB - Control Unit | 1.00 |  |  | True
1 | M00279 | CNC Fab - Steel Parts - Control Unit Base | 1.00 | M00230 | FAB - Control Unit | False
1 | M00280 | CNC Fab - Steel Parts - Control Unit Cover | 1.00 | M00230 | FAB - Control Unit | False
1 | M00367 | CNC USB Controller Mk3/4 | 1.00 | M00230 | FAB - Control Unit | False
1 | M00368 | CNC USB Controller license | 1.00 | M00230 | FAB - Control Unit | False
1 | M00712 | Optocoupler 4 channels | 1.00 | M00230 | FAB - Control Unit | False
1 | M00663 | MicroSD 32GB Samsung Evo+ | 1.00 | M00230 | FAB - Control Unit | False
1 | M00748 | SMPS 1500W 72V 20A (CNC Fab) | 1.00 | M00230 | FAB - Control Unit | False
1 | M00931 | SMPS 60W 24V 2.8A (CNC Pro/Fab) | 1.00 | M00230 | FAB - Control Unit | False
1 | M00853 | USB-C 24V to 5V 3A converter | 1.00 | M00230 | FAB - Control Unit | False
1 | M00502 | Ethernet RJ45 female 50cm, panel mount | 1.00 | M00230 | FAB - Control Unit | False
1 | M00542 | HDMI (female) panel mount to micro HDMI (male) | 1.00 | M00230 | FAB - Control Unit | False
1 | M00619 | PRO/FAB - Limit Switches PCB Assembly | 1.00 | M00230 | FAB - Control Unit | True
2 | M00714 | PCB Custom for CNC Limit Switches | 1.00 | M00619 | PRO/FAB - Limit Switches PCB Assembly | False
2 | M00841 | ALL - Tapped XLR 3 pole female panel, vertical PCB | 6.00 | M00619 | PRO/FAB - Limit Switches PCB Assembly | True
3 | M00917 | XLR 3 pole female panel, vertical PCB | 6.00 | M00841 | ALL - Tapped XLR 3 pole female panel, vertical PCB | False
2 | M00790 | Screw 2 Way PCB Terminal Block 5mm Pitch | 1.00 | M00619 | PRO/FAB - Limit Switches PCB Assembly | False
2 | M00791 | Screwless 4 Way PCB Terminal Block 3.5mm Pitch | 1.00 | M00619 | PRO/FAB - Limit Switches PCB Assembly | False
1 | M00536 | GX12 male 2 pins aux 45cm, panel mount (Emergency Button) | 1.00 | M00230 | FAB - Control Unit | False
1 | M01077 | GX12 male 3 pins aux 45cm, panel mount (Probe) | 1.00 | M00230 | FAB - Control Unit | False
1 | M00852 | USB-A male to A female panel mount, 30cm | 2.00 | M00230 | FAB - Control Unit | False
1 | M01392 | USB-A male to A female panel mount, 50cm, Blue (FAB) | 1.00 | M00230 | FAB - Control Unit | False
1 | M00074 | Axial Fan 24V 92x92mm, panel mount | 1.00 | M00230 | FAB - Control Unit | False
1 | M00515 | Fan cover 92mm | 1.00 | M00230 | FAB - Control Unit | False
1 | M00865 | Wago 3 connectors | 5.00 | M00230 | FAB - Control Unit | False
1 | M00866 | Wago 5 connectors | 4.00 | M00230 | FAB - Control Unit | False
1 | M00746 | Rubber foot M4 | 4.00 | M00230 | FAB - Control Unit | False
1 | M00837 | TFHC M4x35 Black screw | 4.00 | M00230 | FAB - Control Unit | False
1 | M01715 | ISO 7380 M3x4 Black Screw | 40.00 | M00230 | FAB - Control Unit | False
1 | M00552 | Hex spacer M3x30 female/female | 2.00 | M00230 | FAB - Control Unit | False
1 | M00553 | Hex spacer M3x8 female/female | 8.00 | M00230 | FAB - Control Unit | False
1 | M01693 | ISO 7380 M3x10 Black Screw | 12.00 | M00230 | FAB - Control Unit | False
1 | M01702 | Nut DIN934 M4 | 20.00 | M00230 | FAB - Control Unit | False
1 | M00739 | Raspberry Pi 4B 2G | 1.00 | M00230 | FAB - Control Unit | False
1 | M01697 | DIN912 M4x12 Black screw | 16.00 | M00230 | FAB - Control Unit | False
1 | M00540 | GX12 male 5 pins output 45cm, panel mount (VFD, Laser) | 2.00 | M00230 | FAB - Control Unit | False
1 | M00537 | GX12 male 2 pins aux 45cm, panel mount (Safety Enclosure) | 2.00 | M00230 | FAB - Control Unit | False
1 | M00918 | XLR 4 pole female panel M3, Pre-wired 18cm breakout | 4.00 | M00230 | FAB - Control Unit | False
1 | M01070 | Insulated Crimp Bootlace Ferrule | 4.00 | M00230 | FAB - Control Unit | False
1 | M01729 | Dust Filter Mesh ("M"), 7cmx7cmx0.375mm, 0.5mm aperture | 1.00 | M00230 | FAB - Control Unit | False
1 | M00107 | C14 Panel Mount 10A fuse | 1.00 | M00230 | FAB - Control Unit | False
1 | M00530 | Fuse T slow 10A | 1.00 | M00230 | FAB - Control Unit | False
1 | M00744 | Rocker switch DPST, panel mount | 1.00 | M00230 | FAB - Control Unit | False
1 | M00688 | Motor Driver 2DM860H - FAB | 4.00 | M00230 | FAB - Control Unit | False
1 | M00851 | USB-A USB-B cable 30cm Elbow type | 1.00 | M00230 | FAB - Control Unit | False
1 | M00407 | Coloured Washer M3 - Blue | 2.00 | M00230 | FAB - Control Unit | False
1 | M00408 | Coloured Washer M3 - Green | 3.00 | M00230 | FAB - Control Unit | False
1 | M00409 | Coloured Washer M3 - Red | 3.00 | M00230 | FAB - Control Unit | False
1 | M00410 | Coloured Washer M3 - Yellow | 2.00 | M00230 | FAB - Control Unit | False
1 | M00718 | PWM to Analog Voltage Converter 0-10V | 1.00 | M00230 | FAB - Control Unit | False
1 | M00984 | Female Banana Socket - Tab Termination | 1.00 | M00230 | FAB - Control Unit | False

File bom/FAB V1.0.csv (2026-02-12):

level | component_reference | component_name | component_quantity | parent_bom_reference | parent_bom_name | has_child_bom
0 | M01424 | Fab | 1.00 |  |  | True
1 | M00964 | FAB - A - Main Box 1/2 | 1.00 | M01424 | Fab | True
2 | M00230 | FAB - Control Unit | 1.00 | M00964 | FAB - A - Main Box 1/2 | True
3 | M00279 | CNC Fab - Steel Parts - Control Unit Base | 1.00 | M00230 | FAB - Control Unit | False
3 | M00280 | CNC Fab - Steel Parts - Control Unit Cover | 1.00 | M00230 | FAB - Control Unit | False
3 | M00367 | CNC USB Controller Mk3/4 | 1.00 | M00230 | FAB - Control Unit | False
3 | M00368 | CNC USB Controller license | 1.00 | M00230 | FAB - Control Unit | False
3 | M00712 | Optocoupler 4 channels | 1.00 | M00230 | FAB - Control Unit | False
3 | M00663 | MicroSD 32GB Samsung Evo+ | 1.00 | M00230 | FAB - Control Unit | False
3 | M00748 | SMPS 1500W 72V 20A (CNC Fab) | 1.00 | M00230 | FAB - Control Unit | False
3 | M00931 | SMPS 60W 24V 2.8A (CNC Pro/Fab) | 1.00 | M00230 | FAB - Control Unit | False
3 | M00853 | USB-C 24V to 5V 3A converter | 1.00 | M00230 | FAB - Control Unit | False
3 | M00502 | Ethernet RJ45 female 50cm, panel mount | 1.00 | M00230 | FAB - Control Unit | False
3 | M00542 | HDMI (female) panel mount to micro HDMI (male) | 1.00 | M00230 | FAB - Control Unit | False
3 | M00619 | PRO/FAB - Limit Switches PCB Assembly | 1.00 | M00230 | FAB - Control Unit | True
4 | M00714 | PCB Custom for CNC Limit Switches | 1.00 | M00619 | PRO/FAB - Limit Switches PCB Assembly | False
4 | M00841 | ALL - Tapped XLR 3 pole female panel, vertical PCB | 6.00 | M00619 | PRO/FAB - Limit Switches PCB Assembly | True
5 | M00917 | XLR 3 pole female panel, vertical PCB | 6.00 | M00841 | ALL - Tapped XLR 3 pole female panel, vertical PCB | False
4 | M00790 | Screw 2 Way PCB Terminal Block 5mm Pitch | 1.00 | M00619 | PRO/FAB - Limit Switches PCB Assembly | False
4 | M00791 | Screwless 4 Way PCB Terminal Block 3.5mm Pitch | 1.00 | M00619 | PRO/FAB - Limit Switches PCB Assembly | False
3 | M00536 | GX12 male 2 pins aux 45cm, panel mount (Emergency Button) | 1.00 | M00230 | FAB - Control Unit | False
3 | M01077 | GX12 male 3 pins aux 45cm, panel mount (Probe) | 1.00 | M00230 | FAB - Control Unit | False
3 | M00852 | USB-A male to A female panel mount, 30cm | 2.00 | M00230 | FAB - Control Unit | False
3 | M01392 | USB-A male to A female panel mount, 50cm, Blue (FAB) | 1.00 | M00230 | FAB - Control Unit | False
3 | M00074 | Axial Fan 24V 92x92mm, panel mount | 1.00 | M00230 | FAB - Control Unit | False
3 | M00515 | Fan cover 92mm | 1.00 | M00230 | FAB - Control Unit | False
3 | M00865 | Wago 3 connectors | 5.00 | M00230 | FAB - Control Unit | False
3 | M00866 | Wago 5 connectors | 4.00 | M00230 | FAB - Control Unit | False
3 | M00746 | Rubber foot M4 | 4.00 | M00230 | FAB - Control Unit | False
3 | M00837 | TFHC M4x35 Black screw | 4.00 | M00230 | FAB - Control Unit | False
3 | M01715 | ISO 7380 M3x4 Black Screw | 40.00 | M00230 | FAB - Control Unit | False
3 | M00552 | Hex spacer M3x30 female/female | 2.00 | M00230 | FAB - Control Unit | False
3 | M00553 | Hex spacer M3x8 female/female | 8.00 | M00230 | FAB - Control Unit | False
3 | M01693 | ISO 7380 M3x10 Black Screw | 12.00 | M00230 | FAB - Control Unit | False
3 | M01702 | Nut DIN934 M4 | 20.00 | M00230 | FAB - Control Unit | False
3 | M00739 | Raspberry Pi 4B 2G | 1.00 | M00230 | FAB - Control Unit | False
3 | M01697 | DIN912 M4x12 Black screw | 16.00 | M00230 | FAB - Control Unit | False
3 | M00540 | GX12 male 5 pins output 45cm, panel mount (VFD, Laser) | 2.00 | M00230 | FAB - Control Unit | False
3 | M00537 | GX12 male 2 pins aux 45cm, panel mount (Safety Enclosure) | 2.00 | M00230 | FAB - Control Unit | False
3 | M00918 | XLR 4 pole female panel M3, Pre-wired 18cm breakout | 4.00 | M00230 | FAB - Control Unit | False
3 | M01070 | Insulated Crimp Bootlace Ferrule | 4.00 | M00230 | FAB - Control Unit | False
3 | M01729 | Dust Filter Mesh ("M"), 7cmx7cmx0.375mm, 0.5mm aperture | 1.00 | M00230 | FAB - Control Unit | False
3 | M00107 | C14 Panel Mount 10A fuse | 1.00 | M00230 | FAB - Control Unit | False
3 | M00530 | Fuse T slow 10A | 1.00 | M00230 | FAB - Control Unit | False
3 | M00744 | Rocker switch DPST, panel mount | 1.00 | M00230 | FAB - Control Unit | False
3 | M00688 | Motor Driver 2DM860H - FAB | 4.00 | M00230 | FAB - Control Unit | False
3 | M00851 | USB-A USB-B cable 30cm Elbow type | 1.00 | M00230 | FAB - Control Unit | False
3 | M00407 | Coloured Washer M3 - Blue | 2.00 | M00230 | FAB - Control Unit | False
3 | M00408 | Coloured Washer M3 - Green | 3.00 | M00230 | FAB - Control Unit | False
3 | M00409 | Coloured Washer M3 - Red | 3.00 | M00230 | FAB - Control Unit | False
3 | M00410 | Coloured Washer M3 - Yellow | 2.00 | M00230 | FAB - Control Unit | False
3 | M00718 | PWM to Analog Voltage Converter 0-10V | 1.00 | M00230 | FAB - Control Unit | False
3 | M00984 | Female Banana Socket - Tab Termination | 1.00 | M00230 | FAB - Control Unit | False
2 | M00268 | FAB - Mechanical Elements Box (2/3) - Motors | 1.00 | M00964 | FAB - A - Main Box 1/2 | True
3 | M00698 | FAB - Nema34 Motor | 3.00 | M00268 | FAB - Mechanical Elements Box (2/3) - Motors | True
4 | M00699 | Nema34 Stepper Motor 6A 12.7mm Shaft | 3.00 | M00698 | FAB - Nema34 Motor | False
4 | M00919 | XLR4 Male - NC4MXX-BAG | 3.00 | M00698 | FAB - Nema34 Motor | False
3 | M00696 | ALL - Nema23 Motor | 1.00 | M00268 | FAB - Mechanical Elements Box (2/3) - Motors | True
4 | M00697 | Nema23 Stepper Motor 5A 6.35mm Shaft | 1.00 | M00696 | ALL - Nema23 Motor | False
4 | M00660 | Micro-Fit 3.0 Male Connector Housing | 1.00 | M00696 | ALL - Nema23 Motor | False
4 | M00662 | Micro-Fit Male Crimp Terminal Contact | 4.00 | M00696 | ALL - Nema23 Motor | False
3 | M01685 | FAB - Pinion v2 - 2M Z15 80T | 2.00 | M00268 | FAB - Mechanical Elements Box (2/3) - Motors | False
3 | M00085 | FAB - Belt HTD-5M Bag - 15mm 475mm / 95 Teeth | 1.00 | M00268 | FAB - Mechanical Elements Box (2/3) - Motors | True
4 | M00084 | Belt HTD-5M 15mm 475mm / 95 teeth | 2.00 | M00085 | FAB - Belt HTD-5M Bag - 15mm 475mm / 95 Teeth | False
3 | M00102 | FAB - Brush FBL0706 20mm, 250mm length | 2.00 | M00268 | FAB - Mechanical Elements Box (2/3) - Motors | True
4 | M00947 | Brush FBL0706 20mm (m) | 0.50 | M00102 | FAB - Brush FBL0706 20mm, 250mm length | False
2 | M00823 | Square Plate - First CNC Test | 1.00 | M00964 | FAB - A - Main Box 1/2 | False
1 | M00965 | FAB - B - Main Box 2/2 | 1.00 | M01424 | Fab | True
2 | M00254 | FAB - Electronic Components box - FAB-B-1 | 1.00 | M00965 | FAB - B - Main Box 2/2 | True
3 | M01068 | FAB - Motor Cables | 1.00 | M00254 | FAB - Electronic Components box - FAB-B-1 | True
4 | M00271 | FAB - BELRAM lot of Motor Cables | 1.00 | M01068 | FAB - Motor Cables | True
5 | M00691 | Motor cable X 340cm, Red (Fab) | 1.00 | M00271 | FAB - BELRAM lot of Motor Cables | False
5 | M00692 | Motor cable Y1 340cm, Green (Fab) | 1.00 | M00271 | FAB - BELRAM lot of Motor Cables | False
5 | M00693 | Motor cable Y2 530cm, Yellow (Fab) | 1.00 | M00271 | FAB - BELRAM lot of Motor Cables | False
5 | M00694 | Motor cable Z 570cm, Blue (Fab) | 1.00 | M00271 | FAB - BELRAM lot of Motor Cables | False
4 | M00973 | Cable Tie 368mm x 4.8 mm, White | 1.00 | M01068 | FAB - Motor Cables | False
4 | M00659 | Micro-Fit 3.0 Female Connector Housing | 4.00 | M01068 | FAB - Motor Cables | False
4 | M00661 | Micro-Fit Female Crimp Terminal Contact | 14.00 | M01068 | FAB - Motor Cables | False
3 | M00262 | FAB - Inductive Sensor Cables | 1.00 | M00254 | FAB - Electronic Components box - FAB-B-1 | True
4 | M01002 | CNC Fab - Belram lot of Sensor Cables | 1.00 | M00262 | FAB - Inductive Sensor Cables | False
4 | M00599 | Inductive sensor cable Y1- 180cm Green (Fab) | 1.00 | M00262 | FAB - Inductive Sensor Cables | True
5 | M00593 | Inductive sensor cable Unterminated 180cm | 1.00 | M00599 | Inductive sensor cable Y1- 180cm Green (Fab) | False
4 | M00598 | Inductive sensor cable Y1+ 330cm Green (Fab) | 1.00 | M00262 | FAB - Inductive Sensor Cables | True
5 | M00570 | Inductive Sensor Cable Unterminated 330cm | 1.00 | M00598 | Inductive sensor cable Y1+ 330cm Green (Fab) | False
4 | M00600 | Inductive sensor cable Y2- 270cm Yellow (Fab) | 1.00 | M00262 | FAB - Inductive Sensor Cables | True
5 | M00594 | Inductive sensor cable Unterminated 270cm | 1.00 | M00600 | Inductive sensor cable Y2- 270cm Yellow (Fab) | False
4 | M00597 | Inductive sensor cable X- 350cm Red (Fab) | 1.00 | M00262 | FAB - Inductive Sensor Cables | True
5 | M00571 | Inductive Sensor Cable Unterminated 350cm | 1.00 | M00597 | Inductive sensor cable X- 350cm Red (Fab) | False
4 | M00596 | Inductive sensor cable X+ 530cm Red (Fab) | 1.00 | M00262 | FAB - Inductive Sensor Cables | True
5 | M00592 | Inductive sensor cable Unterminated 530cm | 1.00 | M00596 | Inductive sensor cable X+ 530cm Red (Fab) | False
4 | M00601 | Inductive sensor cable Z+ 580cm Blue (Fab) | 1.00 | M00262 | FAB - Inductive Sensor Cables | True
5 | M00595 | Inductive sensor cable Unterminated 580cm | 1.00 | M00601 | Inductive sensor cable Z+ 580cm Blue (Fab) | False
4 | M00973 | Cable Tie 368mm x 4.8 mm, White | 1.00 | M00262 | FAB - Inductive Sensor Cables | False
3 | M00726 | Power Distribution Unit 4-Way, 16A, 4000W | 1.00 | M00254 | FAB - Electronic Components box - FAB-B-1 | False
3 | M00007 | Power Cable C13 IEC to CEE 7/4, Schuko, 2m, 10 A, 250 V | 1.00 | M00254 | FAB - Electronic Components box - FAB-B-1 | False
3 | M00591 | Inductive Sensor PNP NC, M12 | 6.00 | M00254 | FAB - Electronic Components box - FAB-B-1 | False
3 | M01078 | Touch Probe Z Device (3-pins model) | 1.00 | M00254 | FAB - Electronic Components box - FAB-B-1 | False
3 | M00482 | Emergency Stop Button 1NC | 1.00 | M00254 | FAB - Electronic Components box - FAB-B-1 | False
3 | M00848 | USB Key 2Gb | 1.00 | M00254 | FAB - Electronic Components box - FAB-B-1 | False
3 | M00417 | ALL - Control Unit Safety Grounding Cable | 1.00 | M00254 | FAB - Electronic Components box - FAB-B-1 | True
4 | M00609 | Insulated Ring Terminal 0.5mm² to 1.5mm², 22AWG to 16AWG, M4 Stud Size | 1.00 | M00417 | ALL - Control Unit Safety Grounding Cable | False
4 | M00086 | Black Male Banana Connector - Screw Termination, 50V, 16A | 1.00 | M00417 | ALL - Control Unit Safety Grounding Cable | False
3 | M00384 | ALL - Cable Cover for I-type 6 Profile 330mm | 2.00 | M00254 | FAB - Electronic Components box - FAB-B-1 | True
4 | M00383 | Cable Cover for I-type 6 Profile (2m) | 0.34 | M00384 | ALL - Cable Cover for I-type 6 Profile 330mm | False
2 | M00267 | FAB - Mechanical Elements Box - FAB-B-2 (Screws & Nuts) | 1.00 | M00965 | FAB - B - Main Box 2/2 | True
3 | M00234 | FAB - DIN912 Black Screw Bag - M4x12 | 1.00 | M00267 | FAB - Mechanical Elements Box - FAB-B-2 (Screws & Nuts) | True
4 | M01697 | DIN912 M4x12 Black screw | 14.00 | M00234 | FAB - DIN912 Black Screw Bag - M4x12 | False
3 | M00235 | FAB - DIN912 Black Screw Bag - M4x20 | 1.00 | M00267 | FAB - Mechanical Elements Box - FAB-B-2 (Screws & Nuts) | True
4 | M00430 | DIN912 M4x20 Black screw | 4.00 | M00235 | FAB - DIN912 Black Screw Bag - M4x20 | False
3 | M00940 | FAB - DIN912 Black Screw Bag - M4x30 | 1.00 | M00267 | FAB - Mechanical Elements Box - FAB-B-2 (Screws & Nuts) | True
4 | M00939 | DIN912 M4x30 Black screw | 8.00 | M00940 | FAB - DIN912 Black Screw Bag - M4x30 | False
3 | M00236 | FAB - DIN912 Black Screw Bag - M4x45 | 1.00 | M00267 | FAB - Mechanical Elements Box - FAB-B-2 (Screws & Nuts) | True
4 | M00432 | DIN912 M4x45 Black Screw | 4.00 | M00236 | FAB - DIN912 Black Screw Bag - M4x45 | False
3 | M00237 | FAB - DIN912 Black Screw Bag - M4x55 | 1.00 | M00267 | FAB - Mechanical Elements Box - FAB-B-2 (Screws & Nuts) | True
4 | M00433 | DIN912 M4x55 Black Screw | 8.00 | M00237 | FAB - DIN912 Black Screw Bag - M4x55 | False
3 | M00238 | FAB - DIN912 Black Screw Bag - M5x14 | 1.00 | M00267 | FAB - Mechanical Elements Box - FAB-B-2 (Screws & Nuts) | True
4 | M00436 | DIN912 M5x14 Black screw | 8.00 | M00238 | FAB - DIN912 Black Screw Bag - M5x14 | False
3 | M00239 | FAB - DIN912 Black Screw Bag - M5x16 | 1.00 | M00267 | FAB - Mechanical Elements Box - FAB-B-2 (Screws & Nuts) | True
4 | M00437 | DIN912 M5x16 Black screw | 190.00 | M00239 | FAB - DIN912 Black Screw Bag - M5x16 | False
3 | M00240 | FAB - DIN912 Black Screw Bag - M5x20 | 1.00 | M00267 | FAB - Mechanical Elements Box - FAB-B-2 (Screws & Nuts) | True
4 | M01731 | DIN912 M5x20 Black screw | 12.00 | M00240 | FAB - DIN912 Black Screw Bag - M5x20 | False
3 | M00241 | FAB - DIN912 Black Screw Bag - M5x25 | 1.00 | M00267 | FAB - Mechanical Elements Box - FAB-B-2 (Screws & Nuts) | True
4 | M00439 | DIN912 M5x25 Black screw | 8.00 | M00241 | FAB - DIN912 Black Screw Bag - M5x25 | False
3 | M00242 | FAB - DIN912 Black Screw Bag - M5x40 | 1.00 | M00267 | FAB - Mechanical Elements Box - FAB-B-2 (Screws & Nuts) | True
4 | M00442 | DIN912 M5x40 Black screw | 4.00 | M00242 | FAB - DIN912 Black Screw Bag - M5x40 | False
3 | M00243 | FAB - DIN912 Black Screw Bag - M5x50 | 1.00 | M00267 | FAB - Mechanical Elements Box - FAB-B-2 (Screws & Nuts) | True
4 | M00444 | DIN912 M5x50 Black screw | 4.00 | M00243 | FAB - DIN912 Black Screw Bag - M5x50 | False
3 | M00244 | FAB - DIN912 Black Screw Bag - M5x60 | 1.00 | M00267 | FAB - Mechanical Elements Box - FAB-B-2 (Screws & Nuts) | True
4 | M00445 | DIN912 M5x60 Black screw | 4.00 | M00244 | FAB - DIN912 Black Screw Bag - M5x60 | False
3 | M00245 | FAB - DIN912 Black Screw Bag - M6x12 | 1.00 | M00267 | FAB - Mechanical Elements Box - FAB-B-2 (Screws & Nuts) | True
4 | M01718 | DIN912 M6x12 Black screw | 14.00 | M00245 | FAB - DIN912 Black Screw Bag - M6x12 | False
3 | M00246 | FAB - DIN912 Black Screw Bag - M6x16 | 1.00 | M00267 | FAB - Mechanical Elements Box - FAB-B-2 (Screws & Nuts) | True
4 | M01704 | DIN912 M6x16 Black screw | 318.00 | M00246 | FAB - DIN912 Black Screw Bag - M6x16 | False
3 | M00247 | FAB - DIN912 Black Screw Bag - M6x20 | 1.00 | M00267 | FAB - Mechanical Elements Box - FAB-B-2 (Screws & Nuts) | True
4 | M00451 | DIN912 M6x20 Black screw | 66.00 | M00247 | FAB - DIN912 Black Screw Bag - M6x20 | False
3 | M00248 | FAB - DIN912 Black Screw Bag - M6x25 | 1.00 | M00267 | FAB - Mechanical Elements Box - FAB-B-2 (Screws & Nuts) | True
4 | M01748 | DIN912 M6x25 Black screw | 60.00 | M00248 | FAB - DIN912 Black Screw Bag - M6x25 | False
3 | M00258 | FAB - ISO 7380 Black Screw Bag - M5x20 | 1.00 | M00267 | FAB - Mechanical Elements Box - FAB-B-2 (Screws & Nuts) | True
4 | M00566 | ISO 7380 M5x20 Black Screw | 4.00 | M00258 | FAB - ISO 7380 Black Screw Bag - M5x20 | False
3 | M00259 | FAB - ISO 7380 Black Screw Bag - M6x25 | 1.00 | M00267 | FAB - Mechanical Elements Box - FAB-B-2 (Screws & Nuts) | True
4 | M00568 | ISO 7380 M6x25 Black Screw | 8.00 | M00259 | FAB - ISO 7380 Black Screw Bag - M6x25 | False
3 | M00261 | FAB - ISO7379 Shoulder Screw Bag -10X45/M8 | 1.00 | M00267 | FAB - Mechanical Elements Box - FAB-B-2 (Screws & Nuts) | True
4 | M00560 | ISO 7379 M8x45 Shoulder Screw | 2.00 | M00261 | FAB - ISO7379 Shoulder Screw Bag -10X45/M8 | False
3 | M00260 | FAB - ISO7379 Shoulder Screw Bag - 12X50/M10 | 1.00 | M00267 | FAB - Mechanical Elements Box - FAB-B-2 (Screws & Nuts) | True
4 | M00561 | ISO 7379 M10x50 Shoulder Screw | 2.00 | M00260 | FAB - ISO7379 Shoulder Screw Bag - 12X50/M10 | False
3 | M00231 | FAB - DIN9021 Washer Bag - M4x12 | 1.00 | M00267 | FAB - Mechanical Elements Box - FAB-B-2 (Screws & Nuts) | True
4 | M00423 | DIN9021 Washer M4x12 | 14.00 | M00231 | FAB - DIN9021 Washer Bag - M4x12 | False
3 | M00232 | FAB - DIN9021 Washer Bag - M5x15 | 1.00 | M00267 | FAB - Mechanical Elements Box - FAB-B-2 (Screws & Nuts) | True
4 | M00424 | DIN9021 Washer M5x15 | 6.00 | M00232 | FAB - DIN9021 Washer Bag - M5x15 | False
3 | M00233 | FAB - DIN9021 Washer Bag - M6x18 | 1.00 | M00267 | FAB - Mechanical Elements Box - FAB-B-2 (Screws & Nuts) | True
4 | M01694 | DIN9021 Washer M6x18 | 276.00 | M00233 | FAB - DIN9021 Washer Bag - M6x18 | False
3 | M00250 | FAB - DIN985 Lock Nut Bag - M4 | 1.00 | M00267 | FAB - Mechanical Elements Box - FAB-B-2 (Screws & Nuts) | True
4 | M00629 | Lock Nut DIN985 M4 | 24.00 | M00250 | FAB - DIN985 Lock Nut Bag - M4 | False
3 | M00251 | FAB - DIN985 Lock Nut Bag - M5 | 1.00 | M00267 | FAB - Mechanical Elements Box - FAB-B-2 (Screws & Nuts) | True
4 | M00632 | Lock Nut DIN985 M5 | 20.00 | M00251 | FAB - DIN985 Lock Nut Bag - M5 | False
3 | M00252 | FAB - DIN985 Lock Nut Bag - M6 | 1.00 | M00267 | FAB - Mechanical Elements Box - FAB-B-2 (Screws & Nuts) | True
4 | M00630 | Lock Nut DIN985 M6 | 14.00 | M00252 | FAB - DIN985 Lock Nut Bag - M6 | False
3 | M00249 | FAB - DIN985 Lock Nut Bag - M10 | 1.00 | M00267 | FAB - Mechanical Elements Box - FAB-B-2 (Screws & Nuts) | True
4 | M00627 | Lock Nut DIN985 M10 | 2.00 | M00249 | FAB - DIN985 Lock Nut Bag - M10 | False
3 | M00265 | FAB - Spacer Bag - M5x6 | 1.00 | M00267 | FAB - Mechanical Elements Box - FAB-B-2 (Screws & Nuts) | True
4 | M00798 | Spacer M5x6mm | 2.00 | M00265 | FAB - Spacer Bag - M5x6 | False
3 | M00263 | FAB - Spacer Bag - M5x19 | 1.00 | M00267 | FAB - Mechanical Elements Box - FAB-B-2 (Screws & Nuts) | True
4 | M00795 | Spacer M5x19mm | 8.00 | M00263 | FAB - Spacer Bag - M5x19 | False
3 | M00264 | FAB - Spacer Bag - M5x30 | 1.00 | M00267 | FAB - Mechanical Elements Box - FAB-B-2 (Screws & Nuts) | True
4 | M00796 | Spacer M5x30mm | 12.00 | M00264 | FAB - Spacer Bag - M5x30 | False
3 | M00266 | FAB - Spacer Bag - M6x90 | 1.00 | M00267 | FAB - Mechanical Elements Box - FAB-B-2 (Screws & Nuts) | True
4 | M00800 | Spacer M6x90mm | 2.00 | M00266 | FAB - Spacer Bag - M6x90 | False
3 | M00255 | FAB - I-Type Sliding Nut Bag - M4 | 1.00 | M00267 | FAB - Mechanical Elements Box - FAB-B-2 (Screws & Nuts) | True
4 | M00554 | I-Type Sliding Nut M4 | 14.00 | M00255 | FAB - I-Type Sliding Nut Bag - M4 | False
3 | M00256 | FAB - I-Type Sliding Nut Bag - M5 | 1.00 | M00267 | FAB - Mechanical Elements Box - FAB-B-2 (Screws & Nuts) | True
4 | M00555 | I-Type Sliding Nut M5 | 158.00 | M00256 | FAB - I-Type Sliding Nut Bag - M5 | False
3 | M00291 | FAB - V-Wheels Bag - M5 | 1.00 | M00267 | FAB - Mechanical Elements Box - FAB-B-2 (Screws & Nuts) | True
4 | M00882 | Wheel with Bearings for V-slot Profile - Type B | 4.00 | M00291 | FAB - V-Wheels Bag - M5 | False
3 | M00253 | FAB - DIN985 Lock Nut Bag - M8 | 1.00 | M00267 | FAB - Mechanical Elements Box - FAB-B-2 (Screws & Nuts) | True
4 | M00631 | Lock Nut DIN985 M8 | 2.00 | M00253 | FAB - DIN985 Lock Nut Bag - M8 | False
3 | M00955 | FAB - DIN439B JamNut Bag - M8 | 1.00 | M00267 | FAB - Mechanical Elements Box - FAB-B-2 (Screws & Nuts) | True
4 | M00613 | JamNut DIN439B M8 | 18.00 | M00955 | FAB - DIN439B JamNut Bag - M8 | False
3 | M00966 | CNC Fab - Mounting gauge MDF (Frame) | 2.00 | M00267 | FAB - Mechanical Elements Box - FAB-B-2 (Screws & Nuts) | False
3 | M01550 | Cable Trunking Screws Bag | 2.00 | M00267 | FAB - Mechanical Elements Box - FAB-B-2 (Screws & Nuts) | True
4 | M00423 | DIN9021 Washer M4x12 | 10.00 | M01550 | Cable Trunking Screws Bag | False
4 | M01697 | DIN912 M4x12 Black screw | 10.00 | M01550 | Cable Trunking Screws Bag | False
4 | M00554 | I-Type Sliding Nut M4 | 10.00 | M01550 | Cable Trunking Screws Bag | False
3 | M00257 | FAB - I-Type Sliding Nut Bag - M6 | 1.00 | M00267 | FAB - Mechanical Elements Box - FAB-B-2 (Screws & Nuts) | True
4 | M00556 | I-Type Sliding Nut M6 | 368.00 | M00257 | FAB - I-Type Sliding Nut Bag - M6 | False
3 | M00273 | FAB - Offset Spacer Bag - 10x14x12 | 1.00 | M00267 | FAB - Mechanical Elements Box - FAB-B-2 (Screws & Nuts) | True
4 | M00708 | Offset spacer 10x14x12mm | 2.00 | M00273 | FAB - Offset Spacer Bag - 10x14x12 | False
3 | M01686 | FAB - Pinion v2 - Spacer A (12x16x4) Bag | 1.00 | M00267 | FAB - Mechanical Elements Box - FAB-B-2 (Screws & Nuts) | True
4 | M01690 | Spacer -12x16x3 | 2.00 | M01686 | FAB - Pinion v2 - Spacer A (12x16x4) Bag | False
3 | M01687 | FAB - Pinion v2 - Spacer B (12x18x8) Bag | 1.00 | M00267 | FAB - Mechanical Elements Box - FAB-B-2 (Screws & Nuts) | True
4 | M01691 | Spacer - 12x18x8 | 2.00 | M01687 | FAB - Pinion v2 - Spacer B (12x18x8) Bag | False
3 | M01688 | FAB- Pinion v2 - Spacer C (12x18x18) Bag | 1.00 | M00267 | FAB - Mechanical Elements Box - FAB-B-2 (Screws & Nuts) | True
4 | M01692 | Spacer - 12x18x18 | 2.00 | M01688 | FAB- Pinion v2 - Spacer C (12x18x18) Bag | False
3 | M01549 | CUB Brackets Bag | 1.00 | M00267 | FAB - Mechanical Elements Box - FAB-B-2 (Screws & Nuts) | True
4 | M01379 | CU-VFD-Mounting plate 3mm | 4.00 | M01549 | CUB Brackets Bag | False
4 | M00435 | DIN912 M5x12 Black screw | 10.00 | M01549 | CUB Brackets Bag | False
4 | M00746 | Rubber foot M4 | 2.00 | M01549 | CUB Brackets Bag | False
4 | M00555 | I-Type Sliding Nut M5 | 10.00 | M01549 | CUB Brackets Bag | False
3 | M01545 | Cable Management Bag | 1.00 | M00267 | FAB - Mechanical Elements Box - FAB-B-2 (Screws & Nuts) | True
4 | M01551 | SPT - Cable Holder 3d Print | 18.00 | M01545 | Cable Management Bag | False
4 | M00389 | Cable Tie 100mm x 2.5 mm | 28.00 | M01545 | Cable Management Bag | False
2 | M00269 | FAB - Mechanical Elements Box - FAB-B-3 (Feet & Brackets) | 1.00 | M00965 | FAB - B - Main Box 2/2 | True
3 | M00864 | VariBox CHV27 34x26x15 simple cannelure | 1.00 | M00269 | FAB - Mechanical Elements Box - FAB-B-3 (Feet & Brackets) | False
3 | M00063 | Angle Bracket 60 B-Type Groove 8 | 46.00 | M00269 | FAB - Mechanical Elements Box - FAB-B-3 (Feet & Brackets) | False
3 | M00524 | Foot D80 M12x50 + Jam nut M12 + Anti Slip | 6.00 | M00269 | FAB - Mechanical Elements Box - FAB-B-3 (Feet & Brackets) | False
3 | M00488 | End connection plate 30x60 for Foot M12 | 6.00 | M00269 | FAB - Mechanical Elements Box - FAB-B-3 (Feet & Brackets) | False
3 | M00064 | Angle Bracket Simple 20x20 M5 | 4.00 | M00269 | FAB - Mechanical Elements Box - FAB-B-3 (Feet & Brackets) | False
3 | M01329 | FAB - Angle Bracket 30 B-Type Bag | 1.00 | M00269 | FAB - Mechanical Elements Box - FAB-B-3 (Feet & Brackets) | True
4 | M00062 | Angle Bracket 30 B-Type Rainure 6 | 38.00 | M01329 | FAB - Angle Bracket 30 B-Type Bag | False
2 | M01058 | FAB - Mechanical Box - FAB-B-4 (Motion & Miscellaneous Components) | 1.00 | M00965 | FAB - B - Main Box 2/2 | True
3 | M00621 | Linear Block - H20B | 6.00 | M01058 | FAB - Mechanical Box - FAB-B-4 (Motion & Miscellaneous Components) | False
3 | M00622 | Linear Block - W20A Block (Flange) | 4.00 | M01058 | FAB - Mechanical Box - FAB-B-4 (Motion & Miscellaneous Components) | False
3 | M00704 | Nut Housing DSG16H | 2.00 | M01058 | FAB - Mechanical Box - FAB-B-4 (Motion & Miscellaneous Components) | False
3 | M00511 | FF12 Bearing Support | 6.00 | M01058 | FAB - Mechanical Box - FAB-B-4 (Motion & Miscellaneous Components) | False
3 | M00512 | FK12 Bearing Support | 2.00 | M01058 | FAB - Mechanical Box - FAB-B-4 (Motion & Miscellaneous Components) | False
3 | M00270 | FAB - Miscellaneous Components Bag | 1.00 | M01058 | FAB - Mechanical Box - FAB-B-4 (Motion & Miscellaneous Components) | True
4 | M00078 | Ball Bearing 6301-2RS 12x37x12mm | 2.00 | M00270 | FAB - Miscellaneous Components Bag | False
4 | M00364 | CNC Pro/Fab - Steels Parts - Bearing Support Offset Plate | 2.00 | M00270 | FAB - Miscellaneous Components Bag | False
4 | M00390 | Cable Tie 200mm x 4.6 mm, Black | 18.00 | M00270 | FAB - Miscellaneous Components Bag | False
4 | M00411 | Compression Spring 14.5x9.6x1.6mm | 2.00 | M00270 | FAB - Miscellaneous Components Bag | False
4 | M00518 | Flexible Motor Coupler D25L30 - 6.35mm to 10mm | 1.00 | M00270 | FAB - Miscellaneous Components Bag | False
4 | M00519 | Flexible Motor Coupler D30L40 - 12.7mm/5ky to 10mm | 1.00 | M00270 | FAB - Miscellaneous Components Bag | False
4 | M00733 | Pulley HTD-5M 16mm 20 teeth | 2.00 | M00270 | FAB - Miscellaneous Components Bag | False
4 | M00745 | Rubber Bump M8x68 | 6.00 | M00270 | FAB - Miscellaneous Components Bag | False
4 | M00354 | CNC Pro/Fab - Steel Parts - Nut Offset | 2.00 | M00270 | FAB - Miscellaneous Components Bag | False
4 | M00827 | Steel cable tray cantilever arm | 2.00 | M00270 | FAB - Miscellaneous Components Bag | False
4 | M00967 | CNC Fab - Mounting gauge Plywood (Rails) | 1.00 | M00270 | FAB - Miscellaneous Components Bag | False
4 | M01683 | FAB - Acrylic Mounting Gauge (Limits & coupler) | 1.00 | M00270 | FAB - Miscellaneous Components Bag | True
5 | M00716 | PMMA Sheet 3mm 600x400mm, Light Blue | 0.02 | M01683 | FAB - Acrylic Mounting Gauge (Limits & coupler) | False
4 | M01684 | FAB- Pinion v2 - Ball Bearing 6801-ZZ - 12x21x5mm | 2.00 | M00270 | FAB - Miscellaneous Components Bag | False
1 | M00286 | FAB - C - Steel Parts Box 1/2 | 1.00 | M01424 | Fab | True
2 | M00283 | CNC Fab - Steel Parts - R&P drive plate | 2.00 | M00286 | FAB - C - Steel Parts Box 1/2 | False
2 | M00284 | CNC Fab - Steel Parts - Y gantry | 2.00 | M00286 | FAB - C - Steel Parts Box 1/2 | False
2 | M00282 | CNC Fab - Steel Parts - Limit sensor support plate | 4.00 | M00286 | FAB - C - Steel Parts Box 1/2 | False
1 | M00287 | FAB - D - Steel Parts Box 2/2 | 1.00 | M01424 | Fab | True
2 | M00281 | CNC Fab - Steel Parts - Gusset plate | 12.00 | M00287 | FAB - D - Steel Parts Box 2/2 | False
2 | M00359 | CNC Pro/Fab - Steel Parts - Z-axis Top Motor Plate | 1.00 | M00287 | FAB - D - Steel Parts Box 2/2 | False
2 | M00358 | CNC Pro/Fab - Steel Parts - Z-Axis Bottom Bearing Plate | 1.00 | M00287 | FAB - D - Steel Parts Box 2/2 | False
2 | M00360 | CNC Pro/Fab - Steel Parts - X Nut | 1.00 | M00287 | FAB - D - Steel Parts Box 2/2 | False
2 | M00361 | CNC Pro/Fab - Steel Parts - Z Plate | 1.00 | M00287 | FAB - D - Steel Parts Box 2/2 | False
2 | M00285 | CNC Fab - Steel Parts - Y gantry back plate | 1.00 | M00287 | FAB - D - Steel Parts Box 2/2 | False
1 | M00288 | FAB - E - Structure Box 1/3 | 1.00 | M01424 | Fab | True
2 | M00055 | Alu Profile V-3030 (240mm) [1x M6 thread on BOTH sides] | 2.00 | M00288 | FAB - E - Structure Box 1/3 | False
2 | M00081 | Ballscrew SFU1605 250mm & Nut | 1.00 | M00288 | FAB - E - Structure Box 1/3 | False
2 | M00624 | Linear Rail HGR20 (200mm) | 2.00 | M00288 | FAB - E - Structure Box 1/3 | False
2 | M00059 | Alu profile I-6030 (1410mm) | 9.00 | M00288 | FAB - E - Structure Box 1/3 | False
1 | M00289 | FAB - F - Structure Box 2/3 | 1.00 | M01424 | Fab | True
2 | M00060 | Alu profile I-6060 (1410mm) | 6.00 | M00289 | FAB - F - Structure Box 2/3 | False
2 | M00930 | Alu Profile I-6030 (600mm) [2x M6 threads on BOTH sides] | 6.00 | M00289 | FAB - F - Structure Box 2/3 | False
2 | M00956 | Cable Trunking D31mm L500mm | 3.00 | M00289 | FAB - F - Structure Box 2/3 | False
1 | M00290 | FAB - G - Structure Box 3/3 | 1.00 | M01424 | Fab | True
2 | M00058 | Alu profile I-30120 (1530mm) [4x M6 threads on ONE side] | 4.00 | M00290 | FAB - G - Structure Box 3/3 | False
2 | M00061 | Alu profile I-6060 (1530mm) [4x M6 threads on BOTH sides] | 2.00 | M00290 | FAB - G - Structure Box 3/3 | False
2 | M00391 | Cable chain TEZ25.50K 1200mm | 1.00 | M00290 | FAB - G - Structure Box 3/3 | False
2 | M00392 | Cable chain TEZ25.50K 1800mm | 1.00 | M00290 | FAB - G - Structure Box 3/3 | False
2 | M00826 | FAB - Steel cable tray 3000mm (2x1500mm) | 1.00 | M00290 | FAB - G - Structure Box 3/3 | False
2 | M00278 | CNC Fab - Steel Parts - Cable chain holder | 4.00 | M00290 | FAB - G - Structure Box 3/3 | False
2 | M00080 | Ballscrew SFS1620 1500mm & nut | 1.00 | M00290 | FAB - G - Structure Box 3/3 | False
2 | M00103 | FAB - Brush FBL0706 30mm, 1500mm length | 4.00 | M00290 | FAB - G - Structure Box 3/3 | True
3 | M00948 | Brush FBL0706 30mm (m) | 6.00 | M00103 | FAB - Brush FBL0706 30mm, 1500mm length | False
1 | M00946 | FAB - H - Linear rail HGR20 1500mm Box | 1.00 | M01424 | Fab | True
2 | M00626 | Linear rail HGR20 (1500mm) - Docking | 6.00 | M00946 | FAB - H - Linear rail HGR20 1500mm Box | False
1 | M00945 | FAB - I - Straight Rack M2 Box | 1.00 | M01424 | Fab | True
2 | M00831 | Straight Rack M2 DIN5 1005.31mm | 6.00 | M00945 | FAB - I - Straight Rack M2 Box | False
2 | M00832 | Straight rack gauge M2 Q6 500mm | 1.00 | M00945 | FAB - I - Straight Rack M2 Box | False

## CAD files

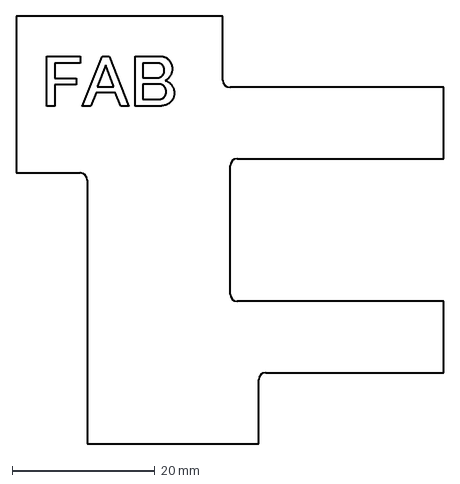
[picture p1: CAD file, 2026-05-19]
cad/FAB Mounting Gauge.dxf
60.0 x 60.0 mm

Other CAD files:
cad/Cable Clip for I-type Groove 6mm.step
cad/VFD-CU V1.2.stp
cad/FAB-CU V1.0.stp
cad/FAB V1.0.stp

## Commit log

2026-02-12 Initial commit with all current files
    [FAB V1.0.stp, FAB-CU V1.0.stp]
2026-02-12 Add image of Fab CNC Milling Machine to README
2026-02-12 Update of the BOM: FAB V1.0
    SKU: M01424
    File: FAB V1.0.csv
    Synced at: Thu Feb 12 11:03:47 UTC 2026
    [FAB V1.0.csv]
2026-02-18 updated readme with cad previews
2026-03-02 Added VFD control unit CAD file
    [VFD-CU V1.2.stp]
2026-03-02 Update of the BOM: FAB-CU V1.0
    SKU: M00230
    File: FAB-CU V1.0.csv
    Synced at: Mon Mar 2 07:55:12 UTC 2026
    [FAB-CU V1.0.csv]
2026-03-02 Update of the BOM: VFD-CU V1.2
    SKU: M00353
    File: VFD-CU V1.2.csv
    Synced at: Mon Mar 2 08:38:01 UTC 2026
    [VFD-CU V1.2.csv]
2026-05-19 Added mounting gauge CAD file
    [FAB Mounting Gauge.dxf]
2026-07-07 Added Cable Clip 3D file
    [Cable Clip for I-type Groove 6mm.step]
